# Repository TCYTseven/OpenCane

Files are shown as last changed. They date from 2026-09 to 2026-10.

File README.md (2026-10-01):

<p align="center">
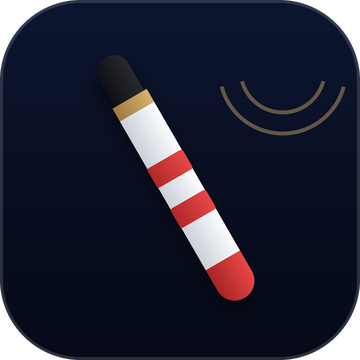
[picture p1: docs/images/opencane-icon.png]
OpenCane app icon: a white cane with red bands on a navy tile
  
</p>

<h1 align="center">OpenCane</h1>

<p align="center"><b>A smart-cane kit that clips an iPhone onto the white cane you already own.</b><br>
LiDAR warnings at waist and head height, haptics through the cane, spatial-audio guidance.<br>
Free where it matters for safety. Open source (MIT).</p>

---

## What OpenCane does

A white cane finds what is on the ground. It misses what is at waist and head height: a low
branch, a truck mirror, a sign bolted at face level. OpenCane clamps an iPhone Pro to the cane and
makes the phone the only computer in the kit:

- **Obstacle detection.** The LiDAR scanner watches the path at waist and head height. The Taptic
  Engine shakes the cane, and "Head height." is spoken before you reach an overhang.
- **Guidance.** GPS and a waypoint engine guide the walk. AirPods Pro play a spatial beacon from the
  direction to walk, and the Apple Watch taps turns and crossings onto the wrist.
- **Hands-free.** Siri, the Action button and "Talk to OpenCane" cover every control, and
  "Where am I" describes the scene, on the phone when there is no network.
- **Hardware you can print.** The mount is 3D-printed ([`hardware/`](hardware/)); nothing needs to
  be bought beyond the phone.

### Free, and OpenCane Premium

| Always free | OpenCane Premium, $49.99/year |
|---|---|
| LiDAR obstacle detection, head-height warnings, drop-off / sign / siren warnings | **Advanced AI object detection**: Hazard watch (cones, barriers, scooters on your route) and people counting |
| Haptics through the cane, spatial audio, speech | **Grok Bot and Family Alerts**: your family hears about a fall, a close call or a low battery |
| Turn-by-turn walking navigation, Apple Watch cues, "Where am I", emergency calling | |

The paywall **never appears during a walk**. Subscriptions run on [RevenueCat](https://www.revenuecat.com).
OpenCane is a social good project, and Premium may be eligible for reimbursement through
insurance, an HSA/FSA or a vision rehabilitation program.

## Screenshots

<p>
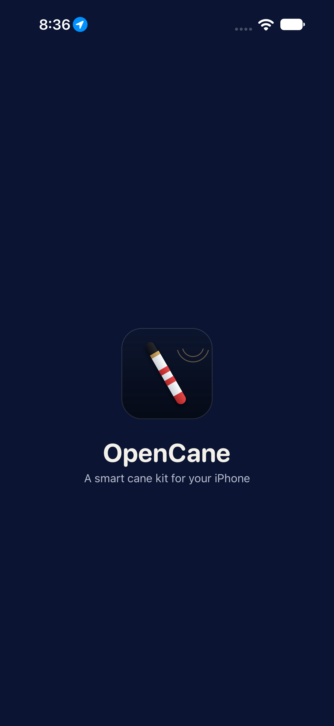
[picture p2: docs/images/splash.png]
OpenCane splash
  
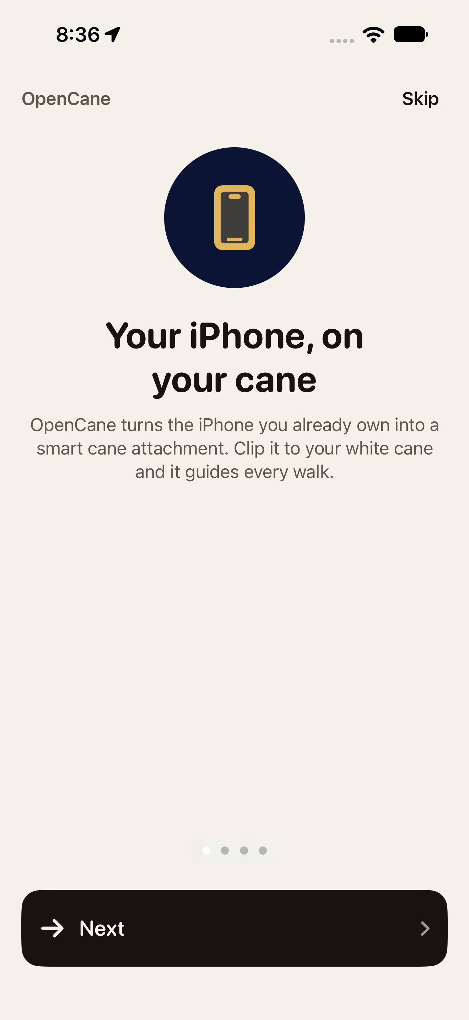
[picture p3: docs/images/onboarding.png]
Onboarding
  
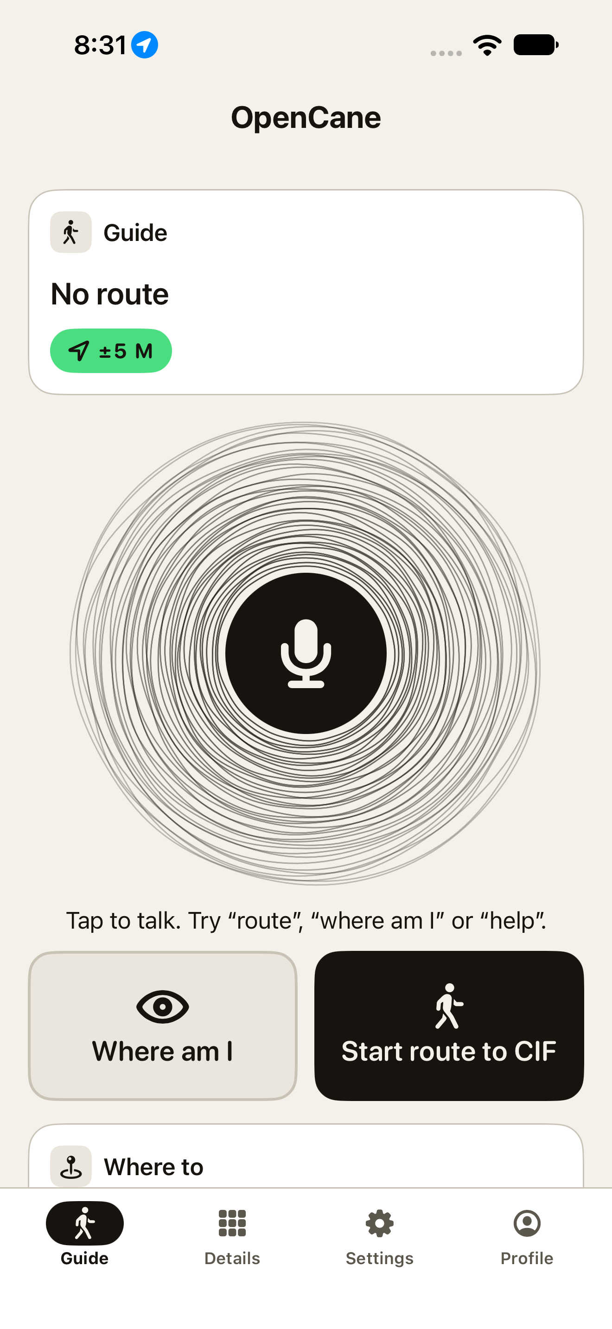
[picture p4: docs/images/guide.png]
Guide
  
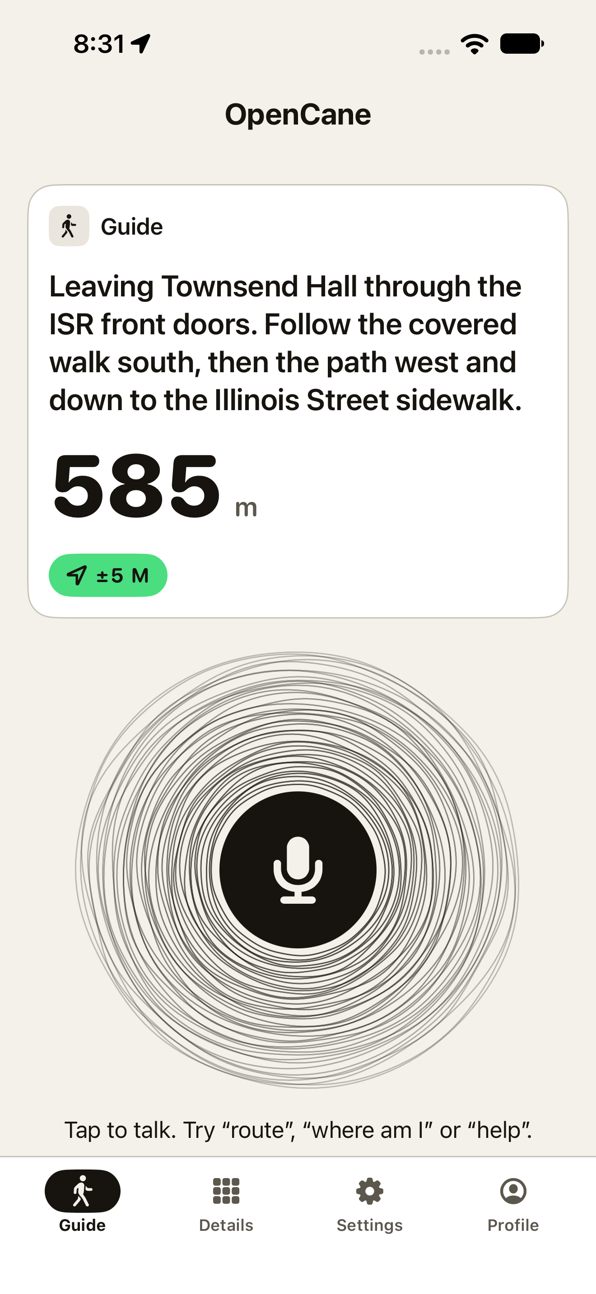
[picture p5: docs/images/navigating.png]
A route in progress
  
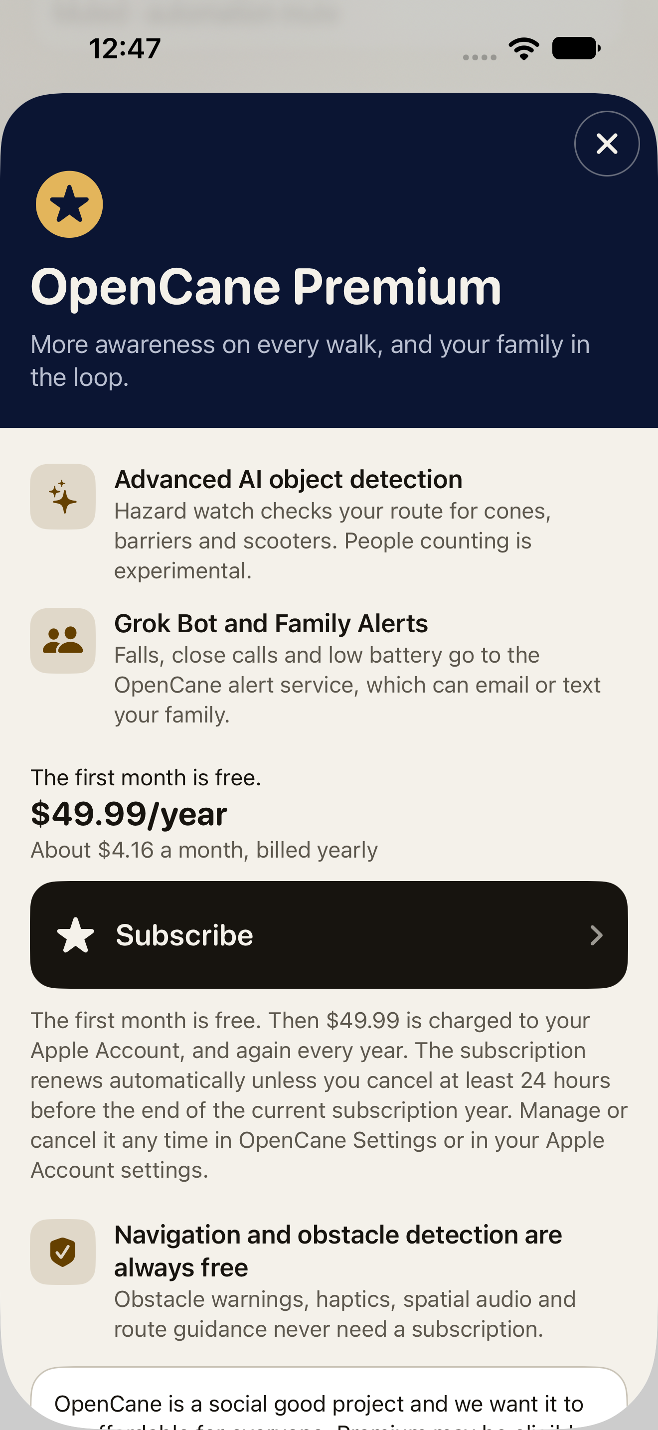
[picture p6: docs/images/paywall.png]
OpenCane Premium paywall at $49.99 a year
  
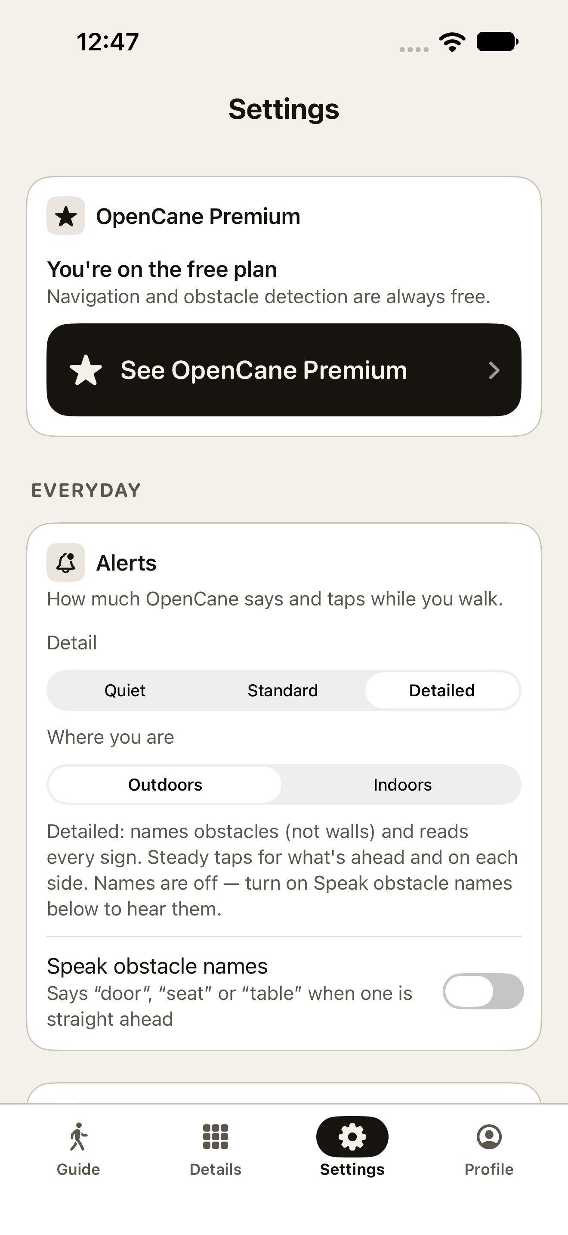
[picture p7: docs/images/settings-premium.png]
Settings showing the free plan
  
</p>

The 1024 App Store icon is [`docs/images/opencane-icon-1024.png`](docs/images/opencane-icon-1024.png).

## Hardware

| Part | Role |
|---|---|
| iPhone with LiDAR (a Pro model; built on an iPhone 17 Pro Max, iOS 27) | The only computer. LiDAR depth, Core Haptics through the cane, GPS + compass, camera |
| Non-metal cane shaft (the prototype uses a 27.65 mm broom handle) | The cane |
| Printed phone mount | Clamps the phone to the shaft: the screwless mount in [`hardware/mount_screwless/`](hardware/mount_screwless/) (print runbook: [`hardware/3d_print_files/README.md`](hardware/3d_print_files/README.md)) |
| AirPods Pro *(optional)* | Spatial-audio beacon, speech, head direction |
| Apple Watch *(optional)* | Wrist taps for turns, crossings and arrival; Repeat / Next / Describe / Recenter |
| Power bank *(recommended)* | ARKit + LiDAR run about 3–4 h on the phone battery |
| Mac with Xcode 27 | Builds and installs. Nothing talks to it at runtime. |

An iPhone without LiDAR installs and guides, and says that obstacle warnings need LiDAR.

## Build and run from a fresh clone

You need a Mac with **Xcode 27** (with the watchOS platform) and **XcodeGen** (`brew install xcodegen`).

```sh
git clone https://github.com/TCYTseven/OpenCane.git
cd OpenCane/ios
make gen        # generates CaneKit.xcodeproj and creates the git-ignored Secrets.plist from the template
make test       # the CaneKitLogic unit tests (no simulator needed)
make sim        # simulator build; the first build downloads the RevenueCat package
open CaneKit.xcodeproj   # then Run the CaneKit scheme on a simulator or your iPhone
```

**Keys** go in `ios/CaneKit/Resources/Secrets.plist`, which is git-ignored and bundled into the app,
so add them before you build. Every key is optional. Without any key the app still runs: the iPhone
voice speaks, "Where am I" answers on the phone, and with no RevenueCat key every feature is
unlocked and Settings says so.

| Key | For |
|---|---|
| `REVENUECAT_API_KEY` | OpenCane Premium. The **public** Apple API key from RevenueCat → Project → API keys (`appl_…`). Never a secret key. |
| `ELEVENLABS_API_KEY` | The natural voice |
| `CUSTOM_*`, `ANTHROPIC_API_KEY`, `GEMINI_API_KEY`, `OPENAI_API_KEY` | The cloud model for "Where am I" and Hazard watch (on-device otherwise) |
| `OPENCANE_GROKBOT_WEBHOOK_URL` / `_KEY` | Family alerts through the Grok Bot routine |

The full list is in [`ios/README.md` §4](ios/README.md#4-secrets-and-permissions).

**On your iPhone:** turn on Developer Mode and pick your team in Xcode (CaneKit target → Signing &
Capabilities), then Run. Or from the command line, put `TEAM` and `DEVICE` in `ios/local.mk` and run
`make run`. [`ios/README.md` §3](ios/README.md#3-build-install-launch) walks through it, and
[`docs/devices_setup.md`](docs/devices_setup.md) covers the AirPods, the watch and an untethered walk.

## Test the paywall

**Fastest: RevenueCat Test Store (simulator or phone, no App Store Connect, no Apple account).**
Put a RevenueCat Test Store key (`test_…`, RevenueCat → Project → API keys) in `Secrets.plist` as
`REVENUECAT_API_KEY`, set up the product, entitlement and offering as in step 1 below under the
project's Test Store app, then from `ios/` run `make uitest-store SIM="<simulator name>"`. It buys
Premium end to end: Details → Hazard watch → paywall ("The first month is free. $49.99/year") →
Subscribe → RevenueCat's "Test valid purchase" → Hazard watch on → Settings "OpenCane Premium is
on". Screenshots land in `ios/build/store-shots`. Or Run from Xcode and tap through it by hand.
The Test Store runs subscription periods fast, so the trial converts in minutes. That is
RevenueCat's test clock, not a bug.

**Judges:** every new install gets the one-month free trial on the annual product. A judge can
also be given Premium: Settings → OpenCane Premium → **Copy support ID**, send it to the team, and
the team pastes it into RevenueCat → Customers → Entitlements → **Grant** `premium`.

A Test Store key only runs the store in a **Debug** build (Xcode Run, the simulator). purchases-ios
stops a Release build that has one ("Wrong API Key", then a crash), so OpenCane skips the store in
that case: a TestFlight build made with a Test Store key opens with every feature unlocked. Use an
App Store key (`appl_…`) for a TestFlight build that should sell Premium.

**Or locally through StoreKit.** Purchases can be tested without App Store Connect, through the StoreKit configuration file
[`ios/StoreKit/OpenCane.storekit`](ios/StoreKit/OpenCane.storekit). It defines one annual
auto-renewing subscription, `opencane_premium_annual`, at $49.99, with a one-month free
introductory offer, and the CaneKit scheme's Run action already selects it.

1. **In RevenueCat:**
   - create a project with an iOS app for the bundle id `com.aritro.canekit`;
   - add the product `opencane_premium_annual`;
   - attach it to an entitlement named `premium`;
   - put it as the Annual package of an offering named `default`, and make that offering current.
2. **In Xcode**, open `ios/StoreKit/OpenCane.storekit`, choose Editor → Save Public Certificate,
   and upload the certificate to the RevenueCat app's settings. That lets RevenueCat validate
   local StoreKit purchases.
3. Put the RevenueCat public API key in `Secrets.plist` as `REVENUECAT_API_KEY`, then build and
   Run from Xcode.
4. Open **Details → Hazard watch** (or Settings → OpenCane Premium → See OpenCane Premium) and
   tap **Subscribe**. The StoreKit test sheet appears. After the purchase the paywall closes and
   the feature is on.
5. To buy again, open Xcode → Debug → StoreKit → Manage Transactions and delete the transaction.
   Refunds, expiry and renewals can be simulated there too.

Settings → OpenCane Premium shows the subscription status, **Restore Purchases** and **Manage
Subscription**. For UI tests without a store, launch with `CANEKIT_PREMIUM=free` or
`CANEKIT_PREMIUM=premium`.

## Tech stack

- **Swift 6** with strict concurrency (main-actor by default), **SwiftUI**, iOS 26 deployment
  target, **XcodeGen** project ([`ios/project.yml`](ios/project.yml)).
- **Apple frameworks:** ARKit + LiDAR scene depth and mesh classification, Core Haptics,
  AVAudioEngine spatial audio (HRTF), AVSpeechSynthesizer, Speech, SoundAnalysis (sirens and horns), Vision, Foundation Models
  (on-device "Where am I"), CoreLocation + MapKit walking directions, WatchConnectivity,
  ActivityKit (Live Activity and Dynamic Island), App Intents (Siri and the Action button),
  HealthKit, StoreKit.
- **RevenueCat** `purchases-ios` for OpenCane Premium: the only third-party package, isolated in
  one file ([`EntitlementManager.swift`](ios/CaneKit/Store/EntitlementManager.swift)).
- **CaneKitLogic**, a pure-Swift package with every rule that has a number in it (lane math, cue
  timing, geofences, the Premium gate) and its Swift Testing suite (975 tests on the last local run; recount with `grep -rhoE '^\s*@Test' ios/Logic/Tests | wc -l`) that also runs on Linux.
- Optional services: ElevenLabs (voice), an OpenAI-compatible, Anthropic, Gemini or OpenAI vision
  model, a Grok Bot routine for family alerts, and Supabase for an opt-in cloud mirror.

## Team

Built at 54FoundersHack in Champaign-Urbana and polished for the RevenueCat Shipaton.
**Aritro**, **Aarav**, **Tejas** (software / iOS app); **Sagar**, **Tommy** (hardware, 3D printing, CAD).

The team is at the University of Illinois Urbana-Champaign and is working with the university
and the [Landuyt Center for Entrepreneurship](https://landuyt.illinois.edu/).

Inside the repo the code is still called **CaneKit**: the Xcode project, targets, the `CaneKitLogic`
module, the `ios/CaneKit/…` paths and the bundle id `com.aritro.canekit`. Only what a person sees
or hears says OpenCane. [`AGENTS.md`](AGENTS.md) → "The name split" explains why.

If you are about to change code, read [Contributing](#contributing) before you edit.

## Recognition

- **First place overall** at 54FoundersHack, 1st of 250.
- **Third place** on the SpaceX track at the same hackathon. SpaceXAI ambassadors are working with the team.
- The launch posts passed **100,000 impressions** on LinkedIn. **More than 100 schools** across the country have written in.
- Funding is in place to keep building.

## Contributing

Read [`AGENTS.md`](AGENTS.md) before the first edit. It wins when documents disagree. The shipped
code wins when a document disagrees with the code: fix the document in the same change.

1. Find the file in [`docs/CODE_REFERENCE.md`](docs/CODE_REFERENCE.md). The data-flow diagram is at the top of that file.
2. A rule with a number in it goes in `ios/Logic` (`CaneKitLogic`) with a Swift Testing test. From `ios/`, `make test` must pass on its own exit code. Never judge it through `| tail`.
3. OpenCane Premium is the one third-party dependency (RevenueCat `purchases-ios`). The gate is [`Premium.swift`](ios/Logic/Sources/CaneKitLogic/Premium.swift), the store client is [`EntitlementManager.swift`](ios/CaneKit/Store/EntitlementManager.swift), the screen is [`PaywallView.swift`](ios/CaneKit/UI/PaywallView.swift), and the walk lock is [`AppModel+Premium.swift`](ios/CaneKit/App/AppModel+Premium.swift). The paywall does not open during a walk. The local product is [`OpenCane.storekit`](ios/StoreKit/OpenCane.storekit): `opencane_premium_annual`, $49.99/year, one month free.
4. Spoken and visible strings say OpenCane. Types, paths, the module and the bundle id stay CaneKit.
5. These paths were removed on purpose. Do not recreate them: `docs/todo.md`, `docs/TEAM_BRIEF.md`, `docs/TEAM_HANDOFF.md`, `docs/ideas.md`, `docs/superpowers/`. The step log is `git log`. [`CHANGELOG.md`](CHANGELOG.md) stays the short submission note.

## Repo map

| Path | What |
|---|---|
| [`AGENTS.md`](AGENTS.md) | **Read before editing.** Hard rules, "How we engineer", commands, and the deliberate behaviours that look like bugs. |
| [`docs/README.md`](docs/README.md) | Index of every doc with when to read it, plus a "Where do I find…" table |
| [`docs/CODE_REFERENCE.md`](docs/CODE_REFERENCE.md) | Map of every file, type and function, with the data-flow diagram |
| [`CHANGELOG.md`](CHANGELOG.md) | Where this submission stands. The step-by-step build log is in git history. |
| [`ios/`](ios/) | The app (code name CaneKit, display name OpenCane): `CaneKit/` iPhone app, `CaneKitWatch/`, `CaneKitWidget/` Live Activity, `Shared/`, `Logic/` SwiftPM package (`CaneKitLogic`, every numeric decision + its unit tests), `CaneKitUITests/`, `project.yml` (XcodeGen), `Makefile`, `scripts/` (test, e2e, cue audit, probes). See [`ios/README.md`](ios/README.md). |
| [`docs/`](docs/) | Design system, hands-free guide, device setup, route evidence, testing plans |
| [`hardware/`](hardware/) | Physical kit: `mount_screwless/` (the live mount, OpenSCAD source), `3d_print_files/` (print runbook; G-code/STLs generated locally), `mount/` (screwed draft + tilt model), `cane_tip/` (printed rolling ball tip) |
| [`scripts/`](scripts/) | Windows mount toolchain (PowerShell + Node): render STLs, slice G-code, verify the screwless mount |
| `firmware/`, `cad/`, `ios/stretch/` | ESP32 grip firmware and OpenSCAD drafts. Stretch / legacy only. |
| [`graphify-out/`](graphify-out/) | Knowledge graph of the repo (code + docs; the committed report lists 6,511 nodes and 15,384 edges, built from `b0db1ebd`). `GRAPH_REPORT.md` lists the communities, `graph.html` opens in a browser (community view, because the graph is over 5,000 nodes). Query it with `graphify query "<question>"`; refresh with `graphify update .` after code changes. |
| `opencane-hardware-brief.html` | One-page hardware brief for a browser |

## Links

- [`AGENTS.md`](AGENTS.md): rules for anyone editing the repo
- [`ios/README.md`](ios/README.md): build, sign, secrets, testing, gotchas
- [`docs/README.md`](docs/README.md): every doc, and where to find things
- [`docs/devices_setup.md`](docs/devices_setup.md): AirPods + Apple Watch + untethered demo checklist
- [`docs/design.md`](docs/design.md): UI and cue design system
- [`docs/cue_design_v2.md`](docs/cue_design_v2.md): research behind the calmer cue design (Steps 35–45)
- [`docs/handsfree.md`](docs/handsfree.md): every voice command and the Action button, for the walker
- [`docs/stress_test_plan.md`](docs/stress_test_plan.md): device tests, failure injection, go/no-go, demo run sheet
- [`hardware/README.md`](hardware/README.md): the printed phone mount (Sagar, Tommy); print runbook in [`hardware/3d_print_files/README.md`](hardware/3d_print_files/README.md)

## License and privacy

OpenCane is released under the [MIT License](LICENSE). The privacy policy is
[`PRIVACY.md`](PRIVACY.md).

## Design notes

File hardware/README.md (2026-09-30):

# hardware/: phone-to-cane mount

> **Printing?** Read [`3d_print_files/README.md`](3d_print_files/README.md) for the print order,
> then generate G-code locally (`scripts/build_stl.ps1` + `scripts/slice_gcode.ps1` on Windows).
> Sliced files are gitignored — they are ~85 MB of build output, not source.

The only new hardware in OpenCane / CaneKit is a mount. It clamps the iPhone 17 Pro Max upright to
the 27.65 mm non-metal stick (measured by the bore rings; it is a broom handle
standing in for a cane), near the grip, with the LiDAR and rear camera facing forward and
~5° down. The phone's own buzz has to be felt through the cane. Everything else (AirPods Pro,
Apple Watch) is off the shelf. This folder replaces the old `cad/` drafts for the phone mount;
those drafts assumed a 12.7 mm cane and an ESP32 grip.

**Sagar owns this folder.** Everything here is a starting point drafted on the software side from
Apple's dimensional drawings and a pitch model. Change the concept, the CAD tool, the geometry and
the print plan with your own ideas and experience. The app needs only four things from any mount:
the phone upright with the rear camera and LiDAR clear and facing forward; the camera 3–8° below
the horizon with the cane held normally (the Mount card shows it live); a firm enough grip that the
phone's buzz is felt in the handle, with nothing magnetic near the phone's bottom edge (compass);
and the shaft out of the camera's view. The product overview is the root
[`README.md`](../README.md).

**Status:** two designs. `mount/` (screwed, this page's quick start) is a
draft nobody has rendered. `mount_screwless/` is the live one: simulated end to end
(`scripts/verify_mount.ps1`: 32 PASS/FAIL lines in a full run, 17 with `-Quick`; all green at Step 25),
sliced, bore rings printed and read; the rest is not yet printed. See `CHANGELOG.md` Steps 21 and 25.

## Files

| File | What it is |
|---|---|
| [`3d_print_files/`](3d_print_files/README.md) | Print-order runbook for the screwless mount. G-code and STLs live here **locally** after `scripts/build_stl.ps1` + `scripts/slice_gcode.ps1`; they are gitignored build artifacts |
| [`mount_screwless/`](mount_screwless/README.md) | The live design: collet clamp + dovetail, zero bought hardware. `screwless_mount.scad` (parts), `coupons.scad` (bore / thread / dovetail fit coupons), `verify.scad` (intersection harness driven by `scripts/verify_mount.ps1`), `PRINTING.md` (operator runbook — read before printing) |
| [`cane_tip/ball_tip.scad`](cane_tip/ball_tip.scad) | Printed rolling ball tip (swivel test, lower, upper, stem), sized to the 27.65 mm prototype stick, not a real cane; rendered by `scripts/build_stl.ps1 -Part swivel_test` etc. |
| `../scripts/` | Windows CAD toolchain for `mount_screwless/` and `cane_tip/`: `build_stl.ps1` (OpenSCAD → binary STL), `verify_mount.ps1` (clearance / mechanism / shell checks), `slice_gcode.ps1` (headless Creality Print slice + material guard), `stl_tools.js` (volume, shells, overhang, support-in-box measurements, node only) |
| [`mount/DESIGN.md`](mount/DESIGN.md) | The design brief: Apple dimensions and sources, what the app needs, requirements, the tilt derivation (**camera 5° down, not 10–20°**), concepts A/B/C, 24 h plan, tooling, print settings, assembly, test protocol |
| [`mount/cane_mount.scad`](mount/cane_mount.scad) | Parametric OpenSCAD model: split collar, rosette hinge with 5° detents and an angle scale, arm, cradle, cap, knob, and an assembly preview. Set `part` to export each STL, already in print orientation. |
| [`mount/test_coupons.scad`](mount/test_coupons.scad) | Bore-fit rings (`pole_d` 27.65 −0.2 / +0 / +0.2 / +0.4), phone-corner fit coupons (gap 0.2 / 0.3 / 0.4), rosette mesh plates |
| [`mount/pitch_model.py`](mount/pitch_model.py) | `python3 mount/pitch_model.py` reproduces the pitch table and the cradle-to-cane clearance check. Edit camera height and FOV after measuring. |

## Quick start (Sagar)

1. Install OpenSCAD (`brew install --cask openscad`; a 2025 development snapshot renders much
   faster). Open `mount/cane_mount.scad` and press F5 with `part = "assembly"`. Look at
   `hinge_angle` 35, 50 and 80. Fix anything it reports.
2. Measure with calipers: the stick Ø where the collar goes, the phone's corner radius
   (`phone_r`), the camera plateau height from the top edge (`plateau_h`), and the button windows.
3. Print `mount/test_coupons.scad` and read it (instructions are in the file header). Set
   `bore_clear`, `clear` and `teeth`.
4. Export and print collar_a, collar_b, arm, cradle, cap and knob in PETG
   (`DESIGN.md` §10).
5. Assemble (`DESIGN.md` §11). Set `hinge_angle` = 95 − cane angle. Run the tests in
   `DESIGN.md` §12 with Aritro.
6. Fine-tune by reading the phone: OpenCane's Mount card shows "Camera tilt N° down · N fps" live.
   Click the hinge until it says **good** (3–8° down) with the cane held the way the walker holds
   it. The same number is in every trip-log `lanes` line as `tilt`.

## Bill of materials

Printed (PETG, light colour; times and masses are estimates, so trust the slicer and the scale):

| Part | Qty | Source | Print | ≈ Mass |
|---|---|---|---|---|
| collar_a (upper half + ear + rosette) | 1 | `cane_mount.scad`, `part = "collar_a"` | ~1.5 h, standing | 30 g |
| collar_b (lower half) | 1 | `part = "collar_b"` | ~1 h, standing | 18 g |
| arm (fin + rosette) | 1 | `part = "arm"` | ~45 min, flat | 16 g |
| cradle | 1 | `part = "cradle"` | ~3.5 h, back down | 30 g |
| cap | 1 | `part = "cap"` | ~30 min, back down | 6 g |
| knob | 1 | `part = "knob"` | ~20 min | 5 g |
| Coupons | 1 set | `test_coupons.scad` | ~40 min | 30 g |

Hardware (no magnets; brass, A4/A2 stainless or nylon only; see `DESIGN.md` R5). **Fridge-magnet
test every screw and nut before use**: reject anything the magnet picks up (cold-worked A2 can
be slightly magnetic).

| Item | Qty | Goes in | Note |
|---|---|---|---|
| M4 × 16 socket-head screw, A2 | 4 | collar clamp | |
| M4 brass heat-set insert, ~8 mm long | 4 | collar_b split face | model hole Ø5.6; check the insert's datasheet |
| M5 × 30 hex bolt, A2 | 1 | hinge | head pressed into the knob (drop of CA) |
| M5 nyloc nut, A2 | 1 | ear pocket | stops the knob backing off from tapping vibration |
| M3 × 8 countersunk screw, A4 (or magnet-tested A2) | 2 | arm → back plate, from the phone side | not nylon: this joint carries the haptics. Heads sit 0.3 mm below the surface; no metal touches the phone |
| M3 brass heat-set insert, 5.7 mm long | 2 | arm root edge | model hole Ø4.0 |
| M3 × 14 screw, nylon preferred | 2 | cap → cradle tabs | next to the phone's top antenna zone |
| M3 nut, nylon preferred | 2 | cradle tab pockets | |
| Right-angle USB-C to USB-C cable, 30–50 cm, plug body ≤ 12 mm | 1 | power | plug turned toward the back of the phone |
| USB-C PD power bank ≥ 5,000 mAh, **not MagSafe** | 1 | strap below the grip or pocket | ≥ 20 cm from the phone (compass) |
| Zip ties 2.5 mm / velcro straps | 5 / 3 | cable routing | slots in the arm and the ear |
| PETG filament | ~150 g | | |
| Paint pen, painter's tape | 1 / 1 | witness marks on screws, hinge, collar | |

Tools: calipers, soldering iron with a heat-set tip, hex keys 2 / 2.5 / 3 mm, 8 mm spanner.

Optional fallback: a Lamicall bike phone holder (15–40 mm clamp, no magnets, ~$30), for a sighted
bench demo only (`DESIGN.md` §7). Do **not** use a Quad Lock MAG or Peak Design SlimLink head:
both put magnets on the phone's back, and the app uses the compass whenever the walker stands
still.

## Who does what

| Who | Owns |
|---|---|
| **Sagar**, **Tommy** (hardware) | Calipers, OpenSCAD render and fixes, coupons, all prints, inserts, assembly, setting the hinge angle, T0 fit, T7 shake, T8 drop, reprints |
| **Aritro**, **Aarav**, **Tejas** (app) | Phone charged; Guided Access (triple-click the side button in OpenCane → Options: Touch, Side Button, Volume Buttons, Keyboards Off, Motion On → Start; then the watch is the only input, see `docs/devices_setup.md` step 4) and the Camera Control setting; app-side tests T2–T6, T9, T10; trip logs; a `CODE_REFERENCE.md` update when the map changes (AGENTS.md rule 10); any `CaneKitLogic` change the tests call for (e.g. `groundSkipFraction`, `DESIGN.md` §13) |
| **Walker** (blindfolded tester) | Holds the cane in their own natural pose for the angle measurement (T1); identifies haptic patterns (T6); walks |
| **Spotter** (sighted teammate) | Walks beside the walker on every outdoor test and films it with a second phone (`ios/README.md`) |

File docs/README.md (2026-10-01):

# Docs index

Every document in the repo, with when to read it. New here, or just pulled? Read the root
[`README.md`](../README.md) (pitch, paywall, and [Contributing](../README.md#contributing)),
then [`AGENTS.md`](../AGENTS.md), then [`ios/README.md`](../ios/README.md).
Open [`CODE_REFERENCE.md`](CODE_REFERENCE.md) when you need a specific file or function.
[`CHANGELOG.md`](../CHANGELOG.md) is the short submission note. The step log is `git log`.

**AI agents:** `AGENTS.md` first (hard rules + "How we engineer"), then `CODE_REFERENCE.md`, then
ask the knowledge graph (`graphify query "<question>"`, see the last row of "Where do I find…").
The code is the newest truth. The step log that used to live in `CHANGELOG.md` is in git history.

**Precedence:** when documents disagree with each other, `AGENTS.md` wins over
`docs/CODE_REFERENCE.md`. When any document disagrees with the shipped code, the code wins and the
doc gets fixed in the same commit. For design tokens, `docs/design.md` is the
spec: when it and `Theme.swift` / `WatchTheme.swift` disagree, fix the Swift. The exception is
screen layout and button labels, where the shipped code (and the tests that pin it) is what's real.

## Every doc

Tracked Markdown plus the one other hand-written doc in the repo
(`opencane-hardware-brief.html`). Nothing else in the repo is documentation; source files document
themselves in their headers (AGENTS.md "How we engineer" 7).

### Repo root

| Doc | Read it when |
|---|---|
| [`README.md`](../README.md) | You want the pitch, the demo, the hardware list, the repo map and the quick start. |
| [`AGENTS.md`](../AGENTS.md) | **Before your first edit, human or AI.** It has the hard rules (concurrency, iOS 26 APIs only, logic lives in `ios/Logic`, secrets, frozen bundle IDs, audio session, speech priorities (rule 8), accessibility-label contract (rule 9), per-commit gate (rule 10)), "How we engineer", the commands, the two false-green traps, the OpenSCAD traps and the "looks wrong but is deliberate" list. It wins every conflict. |
| [`PRIVACY.md`](../PRIVACY.md) | Step 69: the privacy policy the app links to (Settings → About, the paywall). Lists every way data can leave the phone. Change it in the same commit as any new upload path. |
| [`LICENSE`](../LICENSE) | MIT (Step 69). Not Markdown; listed so it is not missed. |
| [`CHANGELOG.md`](../CHANGELOG.md) | Where this release stands and the on-device smoke check. The older step log is in git history. |
| [`opencane-hardware-brief.html`](../opencane-hardware-brief.html) | You want the one-page hardware brief in a browser (added in the Step 21 bore-ring commit). For current print instructions use `hardware/3d_print_files/README.md` instead. |

### iOS app

| Doc | Read it when |
|---|---|
| [`ios/README.md`](../ios/README.md) | You are setting up a Mac, building, signing, installing or testing. It has the day-0 checklist, the Apple spec deviations you must not "fix" (§2, cited by `AGENTS.md` rule 7), every `make` target, secrets and permissions, the automation environment variables, the test layers and counts, how to pull a trip log off the phone, and the depth-map gotchas. |
| [`ios/scripts/streetview/README.md`](../ios/scripts/streetview/README.md) | You want to test the camera features (sign reading, hazard watch, "Where am I") against Google Street View frames of the route, or you need to recapture the git-ignored JPEGs. |
| [`ios/drafts/README.md`](../ios/drafts/README.md) | Rarely. It explains the old iOS 18 starter files, which are not part of any target. |

### `docs/`

| Doc | Read it when |
|---|---|
| [`docs/CODE_REFERENCE.md`](CODE_REFERENCE.md) | You need to find or change code. It maps every file, type and function by module, with the data-flow diagram. |
| [`docs/design.md`](design.md) | You are changing UI, colours or type, or how a cue feels, sounds or shows. §5 maps every cue to its haptic, speech and screen output (§5.1 is speech priorities and the Step 37 talk floor). §6 describes the shipped four-tab layout (Guide / Details / Settings / Profile; §6.8 is the Profile tab, §6.5 has the Family alerts card). §9 is the accessibility-label contract table. |
| [`docs/UX.md`](UX.md) | **Before adding a control of any kind.** Why the interface is a conversation and not a screen: what a button costs a blind walker on a cane-mounted phone (§1), the thesis and its five real failure modes (§2), ten checkable rules (§3), the design — one screen, the two-tier grammar, voice-only mode, input redundancy (§4), what would disprove it (§5). `design.md` still wins on tokens and layout; this wins on *whether a thing should be a button at all*. |
| [`docs/cue_design_v2.md`](cue_design_v2.md) | **Before changing when OpenCane buzzes or speaks.** The Step 35 research: what blind travellers need, where OpenCane violated it, and the proposed calmer cues. Numbers marked **[H]** are hypotheses. |
| [`docs/auditory-load.md`](auditory-load.md) | You are adding or tuning any automatic sound. The Step 30 short research note on blind auditory overload, what OpenCane does about each point, and the open questions for tester walks. `cue_design_v2.md` is the later, fuller research. |
| [`docs/handsfree.md`](handsfree.md) | **You are the walker, or setting the phone up for one.** Every spoken command, what the status answer means, the Settings path for the Action button (and why a locked phone asks to unlock first), what the AirPods stem and Back Tap cannot do, asking a question, and what still needs the screen. |
| [`docs/devices_setup.md`](devices_setup.md) | Before touching the AirPods or the Apple Watch, and before the untethered demo: pairing, Spatial Audio off, the watch app, the voice cache, Guided Access, on-device vision and a symptom → fix table. |
| [`docs/route_isr_cif.md`](route_isr_cif.md) | You are editing `route_isr_cif.json` or re-recording the route on foot. It covers the evidence for every waypoint, OSM node IDs, and which points are still unverified. |
| [`docs/stress_test_plan.md`](stress_test_plan.md) | You are planning device and field tests: facts from the code that change how you test (§0), test levels, the device test matrix (D-tests), failure injection (F-tests), the blindfolded go/no-go checklist and the demo run sheet. |
| [`docs/README.md`](README.md) | This file. |

### Hardware (the printed mount)

| Doc | Read it when |
|---|---|
| [`hardware/README.md`](../hardware/README.md) | You are working on the physical kit (Sagar, Tommy): the four things the app needs from any mount, which of the two designs is live (`mount_screwless/`), the screwed design's files, quick start and bill of materials. |
| [`hardware/3d_print_files/README.md`](../hardware/3d_print_files/README.md) | **You are standing at a printer.** Print order, filament slot, how to read step 1, assembly, what is not settled. G-code/STLs are generated locally (gitignored). |
| [`hardware/mount_screwless/README.md`](../hardware/mount_screwless/README.md) | You are changing the live, no-hardware mount: how it works, build, printer, what to measure before trusting it, the known-unknowns. |
| [`hardware/mount_screwless/PRINTING.md`](../hardware/mount_screwless/PRINTING.md) | Operator runbook for the screwless mount: print list, the one rule, slicing commands, reading the bore rings / thread set / dovetail pair, fitting, calibration. |
| [`hardware/mount/DESIGN.md`](../hardware/mount/DESIGN.md) | You are working on the screwed mount (an unrendered draft) or need the reasoning both mounts share: Apple dimensions, the camera-tilt derivation (3–8° down), concepts, print settings, assembly, test protocol T0–T11. |
| [`cad/README.md`](../cad/README.md) | Stretch / legacy only. The OpenSCAD drafts for the ESP32 grip and sensor pod; they assume a 12.7 mm shaft and are not part of the phone-only demo. |
| [`firmware/README.md`](../firmware/README.md) | Stretch / legacy only. The ESP32 BLE grip firmware, not used for the hackathon. |

### Generated

| Doc | Read it when |
|---|---|
| [`graphify-out/GRAPH_REPORT.md`](../graphify-out/GRAPH_REPORT.md) | You want to know which parts of the repo cluster together, or what a `graphify query` answer is built on. Generated by graphify, never hand-edited. Run `graphify update .` after code changes. The committed graph can lag the tree; trust the code. |

### Outside Markdown

| Where | What |
|---|---|
| [`.github/workflows/ci.yml`](../.github/workflows/ci.yml) | CI. It is **manual-trigger only** (`workflow_dispatch`; Actions tab → CI → Run workflow) because the account's GitHub Actions billing is exhausted. Jobs: Logic tests on Linux, an informational simulator build on macOS. The local `make` gate is authoritative. |
| `ios/Makefile` header | The one-line list of make targets (the full table is `ios/README.md` §3). |
| `scripts/*.ps1`, `scripts/stl_tools.js` (repo root) | Windows mount toolchain: `build_stl.ps1` (render every printable), `slice_gcode.ps1` (headless slicing + verification), `verify_mount.ps1` (the screwless-mount checks), `stl_tools.js` (the STL/G-code measurements they use). Each has a usage header. |
| `~/.claude/plans/phone-is-king-glittery-bee.md` | The approved build plan, on Aritro's Mac only (it is not in the repo). |

## Where do I find…

| I need… | Look here |
|---|---|
| **Build / run commands** | [`ios/README.md` §3](../ios/README.md#3-build-install-launch) (table of every `make` target) and the header of `ios/Makefile`. Run everything from `ios/`. |
| **Signing setup (team, device)** | `ios/local.mk`, which is git-ignored and holds `TEAM = …` and `DEVICE = …`. See [`ios/README.md` §1](../ios/README.md#1-day-0-checklist). |
| **The route file** | `ios/CaneKit/Resources/route_isr_cif.json` (9 waypoints, 989 m). Evidence is in [`route_isr_cif.md`](route_isr_cif.md). The schema is `ios/Logic/Sources/CaneKitLogic/Waypoint.swift`, pinned by `RouteTests.swift`. Other destinations use MapKit via `ios/CaneKit/Navigation/RouteSource.swift`; campus names ("take me to Siebel") resolve through `CampusPlaces.swift`. |
| **Navigation rules (fences, veer, arrival, turn settling)** | `ios/Logic/Sources/CaneKitLogic/GeoMath.swift` (`GeofenceTracker`, `OffCourseDetector`), `CourseSmoother.swift` and `NavSupport.swift` (`TurnSettle`, `StraightWalkDetector`). The engine is `ios/CaneKit/Navigation/NavigationEngine.swift`. The reasons are in `AGENTS.md` → "Things that look wrong but are deliberate". |
| **Speech rules (priorities, interruption, resume, Repeat)** | `AGENTS.md` rule 8 and its deliberate-behaviour list. The code is `ios/CaneKit/Speech/SpeechQueue.swift`, `CueSpeechPolicy` in `NavSupport.swift`, `SpeechLoadPolicy.swift` (optional-speech calm window), `SpeechResume.swift` (Step 37: a cut line resumes from its clause; 0.35 s pause between bands) and `ElevenLabsVoice.swift` (natural voice + cache). The cue table is [`design.md` §5](design.md#5-cue-mapping-every-cue--felt-heard-shown). |
| **Cue detail levels (Quiet / Standard / Detailed × Outdoors / Indoors)** | `CueRules`, `CueLevel`, `CuePlace` in `ios/Logic/Sources/CaneKitLogic/CueProfile.swift` (Step 36; tested in `CueProfileTests.swift`). Persisted as `AppModel.cueLevel` / `cuePlace`, default Detailed + Outdoors; the Settings → Cues card. Research: [`cue_design_v2.md`](cue_design_v2.md). |
| **Haptic patterns** | Phone: `ios/CaneKit/Haptics/HapticPlayer.swift` (obstacles: left 2 taps, right 3, head 2 hard hits, centre Geiger loop 2 Hz at 2 m → 8 Hz at 0.5 m; route: long buzzes, turn left 1, right 2, crossing 3, arrived long-short-long; ground hazard: 4 heavy taps). *When* a cue fires: `CueDecider.swift` + `GeigerRate` in `ios/Logic`. Wrist: the `WKHapticType` map in `ios/CaneKitWatch/WatchModel.swift`. |
| **Watch messages (phone ↔ watch)** | The wire contract is `ios/Logic/Sources/CaneKitLogic/WatchMessage.swift` (JSON under key `"m"`, tested in `WatchMessageTests.swift`). The phone side is `ios/CaneKit/Watch/PhoneWatchLink.swift` and the watch side is `ios/CaneKitWatch/WatchModel.swift`. |
| **Voice commands, Siri, Action button, conversation** | `ios/CaneKit/App/AppIntents.swift`, `App/HandsFreeIntents.swift`, `ios/CaneKit/Conversation/` (`ConversationCoordinator`, `VoiceInputEngine`, `PostStore`), and the Logic side `ConversationModels.swift` / `FastPathIntentClassifier.swift` / `ConversationPrompt.swift` / `QuestionPrompt.swift` / `StatusSummary.swift`. The walker's view is [`handsfree.md`](handsfree.md). |
| **Flashlight / both cameras** | `TorchSwitch.swift` and `LiveView.swift` (`BothCameras`, `FaceTrackingChange`) in `ios/Logic` (Step 34). |
| **Secrets / API keys** | The template is `ios/Secrets.example.plist`. Real keys go only in `ios/CaneKit/Resources/Secrets.plist`, which is git-ignored: never commit or print it. The reader is `ios/CaneKit/Scene/Secrets.swift`. The key list is in [`ios/README.md` §4](../ios/README.md#4-secrets-and-permissions). |
| **OpenCane Premium** | Gate: `ios/Logic/Sources/CaneKitLogic/Premium.swift`. Store: `ios/CaneKit/Store/EntitlementManager.swift` (free month only when `IntroEligibilityStatus.eligible`). Screen: `ios/CaneKit/UI/PaywallView.swift`. Walk lock: `ios/CaneKit/App/AppModel+Premium.swift`. Local product: `ios/StoreKit/OpenCane.storekit` (`opencane_premium_annual`, $49.99/year, free `P1M`). The paywall does not open during a walk. |
| **Testing** | See [`ios/README.md` §5](../ios/README.md#5-testing). Logic tests are in `ios/Logic/Tests/CaneKitLogicTests/` (`make test`; 965 `@Test` annotations in 74 files on the last recount; recount before quoting). UI tests, the screenshot tour and the Dynamic Island tour are in `ios/CaneKitUITests/` (`make uitest` runs all 13, `make tour` and `make island` one suite each). GPS-replay end-to-end runs through `ios/scripts/e2e.py` (`make e2e`). Automation is silent under `CANEKIT_MUTE=1` / `CANEKIT_UITEST=1`. |
| **Accessibility labels the tests depend on** | `AGENTS.md` rule 9 lists them. The details are in `CODE_REFERENCE.md` → module `ui-tests-build` and `design.md` §9. |
| **UI tokens and components** | `ios/CaneKit/UI/Theme.swift` (`CKColor`, `CKFont`, `CKBigButton`, …) and `ios/CaneKitWatch/WatchTheme.swift`. The spec is [`design.md`](design.md), which wins on token values. |
| **Trip log (what happened on a walk)** | `ios/CaneKit/Trip/TripLogger.swift` writes `canekit-<stamp>.jsonl` to the app's Documents folder. Get it with the Files app (On My iPhone → OpenCane), with `cd ios && make audit` (pulls the newest log off the phone in `local.mk` and measures its cue load), or with the `xcrun devicectl … --domain-type appDataContainer --domain-identifier com.aritro.canekit` commands in [`ios/README.md` §5](../ios/README.md#5-testing). |
| **Cue-load numbers for a walk** | `ios/scripts/cue_audit.py` (`make audit`, or `make audit LOG=path`): mounted vs handheld, head band wall vs overhang, cues and spoken lines per minute, replays and resumes. |
| **Hazards (drop-offs, signs, hazard watch, hazard map)** | Decisions: `ios/Logic/Sources/CaneKitLogic/Hazards.swift` (tested in `HazardTests.swift`). App side: `ios/CaneKit/Depth/GroundSampler.swift`, `ios/CaneKit/Scene/HazardScanner.swift`, `OnDeviceVision.swift`, `ios/CaneKit/Trip/HazardLog.swift`, `ios/CaneKit/UI/HazardsCard.swift`. |
| **Mount angle** | `MountTilt` in `ios/Logic/Sources/CaneKitLogic/LaneReport.swift`; live on the Mount card; derivation in `hardware/mount/DESIGN.md`. |
| **Street View mock** | `ios/CaneKit/Depth/FrameReplay.swift`, `ios/scripts/streetview/`, `ios/scripts/vision_probe.swift`, `ios/scripts/sign_probe.swift`, `make uitest-streetview`, `make e2e SCENARIO=streetview`. Not the app: `ios/scripts/streetview_stim.py` (commit `d775d4b`, run by hand) is a stand-alone visualiser over the same frames with its own approximate navigation and template narration. |
| **Project / targets / Info.plist / entitlements** | `ios/project.yml` (XcodeGen). Regenerate with `make gen` only when `project.yml` or the file list changed. Never hand-edit `CaneKit.xcodeproj`. |
| **Open work** | Git history holds the old step checklist. Field testing: [`stress_test_plan.md`](stress_test_plan.md). |
| **The knowledge graph** | `graphify-out/` at the repo root (`GRAPH_REPORT.md` lists the communities; `graph.html` opens in a browser; `graph.json` is the data). Ask it from the repo root with `graphify query "<question>"`, `graphify path "A" "B"` or `graphify explain "X"`. After code changes, refresh it with `graphify update .` (code only) or `/graphify . --update` in Claude Code. Install once with `uv tool install graphifyy` (the build Mac has graphifyy 0.9.44). |

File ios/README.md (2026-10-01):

# OpenCane: the iOS app for the phone-only smart cane

> **The name split.** The product a person sees, hears and says to Siri is **OpenCane** (that is
> `CFBundleDisplayName` in `project.yml`). Everything in the build is still called **CaneKit**: the
> Xcode project, the targets and scheme, `PRODUCT_NAME`, the `CaneKitLogic` module, the
> `ios/CaneKit/…` paths, the Makefile and the frozen bundle ids `com.aritro.canekit*`. That is
> deliberate (AGENTS.md → "The name split"), so every command and path in this file still matches
> the files on disk. Do not rename the code.

This is a native SwiftUI app in Swift 6 with strict concurrency (main-actor default isolation). It
builds against iOS 26 / watchOS 26. Apple frameworks do the sensing and the speech. The one
third-party package is RevenueCat (`purchases-ios`), isolated in
`ios/CaneKit/Store/EntitlementManager.swift`. The hardware is an iPhone 17 Pro Max on iOS 27
(LiDAR, Action button, Camera Control) clamped to a non-metal stick (27.65 mm, measured by the
bore-ring coupons; a broom handle stands in for the cane), plus AirPods Pro and an Apple Watch.
For the demo everything runs **untethered on the phone**. The Mac only signs and installs.

| Target / package | What it is | Bundle ID (frozen) |
|---|---|---|
| **CaneKit** (shown as **OpenCane**) | The iPhone app, and the only computer in the kit | `com.aritro.canekit` |
| **CaneKitWatch** | watchOS companion: wrist taps, Repeat / Next / Describe / Recenter | `com.aritro.canekit.watchkitapp` |
| **CaneKitWidget** | Live Activity (Dynamic Island + lock screen) | `com.aritro.canekit.widget` |
| **CaneKitUITests** | XCUITests + the screenshot tour | `com.aritro.canekit.uitests` |
| **CaneKitLogic** (`Logic/`) | SwiftPM package with every pure decision that has a number in it, plus its Swift Testing tests. Runs without Xcode. | — |

Start with [`AGENTS.md`](../AGENTS.md) (hard rules; it wins every conflict), then
[`docs/CODE_REFERENCE.md`](../docs/CODE_REFERENCE.md), which maps every file, type and function and
has the **data-flow diagram** ([§ Data flow](../docs/CODE_REFERENCE.md#data-flow)). Before the
AirPods, the watch or the untethered demo, read [`docs/devices_setup.md`](../docs/devices_setup.md).
Every other doc is listed in [`docs/README.md`](../docs/README.md).

**Where the work stands.** Obstacle detection, haptics, spatial audio, speech, navigation and
emergency calling stay free. OpenCane Premium (Hazard watch, Name people ahead, and Family Alerts) is the store:
the gate is `ios/Logic/Sources/CaneKitLogic/Premium.swift`, the client is
`ios/CaneKit/Store/EntitlementManager.swift`, the screen is `ios/CaneKit/UI/PaywallView.swift`.
The paywall does not open during a walk. It says the first month is free only when RevenueCat
says this Apple Account is still eligible. Setup for the product, the entitlement `premium` and
the offering `default` is in the root README, "Test the paywall". The short submission note is
[`CHANGELOG.md`](../CHANGELOG.md). The step log is `git log`. There is no `docs/todo.md`.

Recount tests from `ios/` with `grep -rhoE '^\s*@Test' Logic/Tests | wc -l`. Do not quote a count
from this file; it goes stale.

The safety line also includes the route-time `SensorModeInterlock` (face/high-rate changes
cannot restart ARKit during navigation), the generation-fenced `VoiceInputGuard` lifecycle
(route/interruption/permission/engine failures stop push-to-talk and restore playback), GPS freshness
fencing, terminal AR cleanup, and explicit cloud/people-detection consent gates. Recount the
tests with `grep -rhoE '^\s*@Test' Logic/Tests | wc -l` after every merge. Do not keep a frozen count in this file.

## Layout

| Path | Contents |
|---|---|
| `CaneKit/` | The phone app: `App/` (`AppModel` owns every engine; App Intents and hands-free intents), `Conversation/` (voice input, conversational assistant), `Alerts/` (family alerts: `FamilyAlerts`, `GrokBotClient`, `FallWatcher`, `AlertSummarizer`), `Cloud/` (`CloudSync`, `SupabaseClient`), `Depth/`, `Haptics/`, `Speech/`, `Audio/` (beacon, sound watcher), `Navigation/`, `Scene/`, `Trip/` (trip log, `LiveActivityController`, `MedicalProfileStore`), `Watch/`, `UI/` (incl. `ProfilePage`), `Resources/` (`route_isr_cif.json`, assets, your git-ignored `Secrets.plist`) |
| `CaneKitWatch/`, `CaneKitWidget/`, `CaneKitUITests/` | The targets above |
| `Shared/LiveActivity/` | `NavActivityAttributes`, compiled into the app and the widget |
| `Logic/` | `CaneKitLogic`, 77 source files, including `Premium.swift`. Family alerts and safety events: `FamilyAlertPolicy`, `FamilyContacts`, `GrokBotEvent`, `AlertContext`, `FallDetector`, `ThreatWatch`, `ActionRateLimit`. Live Activity: `LiveActivityCoalescer`. Step 47: `TorsoHapticPolicy`, `SceneEngineSummary`. Depth and obstacles: `LaneMath`, `LaneReport`, `DepthSnapshot`, `DepthReadiness`, `MultiCamDepth`, `CueDecider`, `PeopleAhead`, `Hazards`, `SensorModeInterlock`. Cues and speech: `CueProfile` (`CueRules`), `SpeechResume`, `SpeechLoadPolicy`, `SpokenPhrases`, `UtteranceEnd`, `VoicePrefetch`. Navigation: `GeoMath`, `CourseSmoother`, `NavSupport`, `NavigationHealth`, `TripRefreshGeneration`, `Waypoint`, `CampusPlaces`, `DestinationSuggestions`. Scene: `VLMCodec`, `SceneVocabulary`, `CloudSceneGate`, `PeopleDetection`. Hands-free and conversation: `ConversationModels`, `ConversationPrompt`, `FastPathIntentClassifier`, `HeadNodDetector`, `QuestionPrompt`, `StatusSummary`, `VoiceInputGuard`. Devices and app state: `WatchMessage`, `HeadYawSources`, `SoundAlerts`, `SoundRecognitionGuard`, `TorchSwitch`, `LiveView`, `LaunchRecovery`, `StopRouteConfirmation`, `TripLogRecord`. Plus `Tests/` |
| `project.yml` | XcodeGen spec. `CaneKit.xcodeproj` is generated and git-ignored. |
| `Makefile`, `scripts/` | `gen.sh` (project generation), `test.sh` (logic tests), `e2e.py` (GPS-replay end-to-end), `cue_audit.py` (cue load of one trip log, `make audit`), `vision_probe.swift` / `sign_probe.swift` (on-device Vision and sign-reading range against Street View frames), `streetview/` (`frames.json` + git-ignored JPEGs), `streetview_stim.py` (run by hand, no Makefile target: a stand-alone Street View walk visualiser that shells out to `vision_probe.swift` and writes `build/streetview_stim/`; it runs no app code, so use `make e2e SCENARIO=streetview` for what the app says), `appicon.py` (renders the app icon) |
| `Secrets.example.plist` | Template for `CaneKit/Resources/Secrets.plist` |
| `local.mk` | Git-ignored, and you create it: `TEAM` and `DEVICE` for device builds |
| `stretch/`, `drafts/` | Not in any target (old ESP32 BLE client, iOS 18 starter files). Leave them alone. |

---

## 1. Day-0 checklist

These steps are done once per Mac and per phone. On the build Mac they are done: Xcode 27 RC
(27A266a) and XcodeGen 2.46.0 are installed, `ios/local.mk` exists, and the app has been installed
on the phone with `make run` (CHANGELOG Steps 35 and 37). A second Mac or phone needs all of them.

1. Install **Xcode 27 RC** (developer.apple.com/download; ~15 GB installed). The phone runs iOS 27,
   so Xcode 26 cannot deploy to it. The deployment target stays **iOS 26 / watchOS 26**.
   ```sh
   sudo xcode-select -s /Applications/Xcode.app
   sudo xcodebuild -license accept
   xcodebuild -runFirstLaunch
   xcodebuild -downloadPlatform watchOS      # separate download; the watch target fails without it
   brew install xcodegen                     # 2.46.0
   ```
2. Open Xcode once → Settings → Accounts → add your Apple ID. A free **Personal Team** appears. An
   install expires after 7 days, and the team gets 10 App IDs per week. We use 3, so never rename
   bundle IDs. Then run `cd ios && make gen`, open `ios/CaneKit.xcodeproj` once, select the
   **CaneKit** target → **Signing & Capabilities** and pick the Personal Team. That creates the
   Apple Development certificate (until it exists, `security find-identity -v -p codesigning`
   lists nothing). Your **Team ID** is shown in Xcode → Settings → Accounts → the team's details,
   or read it from the certificate and use the `OU=` value:
   ```sh
   security find-certificate -c "Apple Development" -p | openssl x509 -noout -subject
   ```
   The 10 characters in parentheses of an "Apple Development: Name (…)" identity are **not** the
   Team ID.
3. iPhone **and** Watch: Settings → Privacy & Security → **Developer Mode** → on (this reboots).
4. Plug the phone in and open Xcode → Window → Devices. The paired watch shows under the phone,
   which registers its UDID. Watch pairing over Wi-Fi is flaky: if the watch isn't paired within
   30 min, the watch app becomes a day-2 item.
5. Run `cd ios && make devices` and copy the phone's identifier. Then create `ios/local.mk`:
   ```make
   TEAM   = ABCDE12345                # the OU= value from step 2
   DEVICE = 00008150-000A1B2C3D4E5F   # make devices
   ```
6. First install (`make run`), then on the phone: Settings → General → VPN & Device Management →
   trust the developer app.
7. Phone Settings → Action Button → Shortcut → OpenCane → **Talk to OpenCane** (the target
   `docs/handsfree.md` §3 recommends; one press listens, and "What is in front of me?" covers the
   scene) or **Where am I** (scene only). The shortcuts appear after the first launch.
8. Settings → Bluetooth → (i) next to the AirPods → **Spatial Audio: Off** and **Head Tracking: Off**.
   System head-tracking would re-spatialize the beacon. The rest of the AirPods and watch list is in
   `docs/devices_setup.md`.

## 2. Verified spec deviations (don't "fix" these back)

| Spec said | Reality (Apple docs, checked | What CaneKit does |
|---|---|---|
| `AVAudioEnvironmentNode.isListenerHeadTrackingEnabled` | Needs the **Head Pose** capability, which is paid-team only | `CMHeadphoneMotionManager` yaw (relative, drifts) drives `listenerAngularOrientation`. **Recenter** comes from the phone or watch button, or auto-recenter when walking straight (`StraightWalkDetector`: 3 steady fixes, never within 15 m of a crossing). The beacon ignores head yaw until the first recenter after a turn. |
| Watch side button = "next" | There is no API for the side button or a crown *press* | Crown rotation (3 detents within 1 s of the first) + big on-screen Repeat / Next / Describe / Recenter |
| Camera Control press = describe | `AVCaptureEventInteraction` only fires for apps "actively performing capture". Unverified with ARKit owning the camera. | Spike built (`Scene/CameraControlInteraction.swift`; a press is logged as `describe {trigger: cameraControl}` in the trip log — the debug footer that counted presses went in Step 11). The Action button, the watch and the on-screen button are the guaranteed paths. |
| Watch haptics on demand | `WKInterfaceDevice.play` no-ops unless the watch app is frontmost, and `sendMessage` needs reachability | The watch runs a walking `HKWorkoutSession` (HealthKit on the watch target) so cues play wrist-down, with a `WKExtendedRuntimeSession` fallback |
| Haptic rate ∝ 1/distance | `sendParameters` can't retime events | Geiger loop: one pre-built transient player fired on a timer, 2 Hz at 2 m → 8 Hz at 0.5 m |
| One audio session | Mixing `.playback` / `.playAndRecord` / HFP flips AirPods routes | `.playback`, mode `.default`, `[.duckOthers]`, no Bluetooth options. TTS uses the app session. Haptics use `CHHapticEngine(audioSession: nil)`. |
| XcodeGen project | 2.46.0 embeds the watch app in `Watch/` (bug #1613, Xcode 26+) | `scripts/gen.sh` patches the pbxproj after generating. `WATCH=0 scripts/gen.sh` gives a phone-only project. |

Also: mesh classification ("Two meters ahead, door") is an **indoor** feature. LiDAR range is ~5 m and
sunlight kills it. Outdoors the product is the lanes (distance only). Demo doors are at the ISR
lobby and the CIF entrance. Since Step 36 names are spoken only with "Speak obstacle names" on (default
off) and the Settings → Cues place on **Outdoors**: the Indoors place names nothing (`CueRules`).

## 3. Build, install, launch

Everything runs from `ios/` on the command line. You don't need the Xcode GUI after day 0.
`TEAM` and `DEVICE` come from `local.mk`, and you can override either on the command line
(`make build DEVICE=…`).

| Command | What it does |
|---|---|
| `make gen` | `scripts/gen.sh`: `xcodegen generate` + the watch-embed patch, and it copies `Secrets.example.plist` → `CaneKit/Resources/Secrets.plist` if missing. Run it only after `project.yml` or the file list changes. `WATCH=0 scripts/gen.sh` gives a phone-only project. |
| `make test` | `scripts/test.sh`: the `CaneKitLogic` Swift Testing suite (975 tests, 1 known issue, on the last local run). Recount with `grep -rhoE '^\s*@Test' Logic/Tests | wc -l`. Works with the Swift 6 toolchain / Command Line Tools; never touches the simulator or xcodebuild. Extra arguments pass through to `swift test` only when you call `scripts/test.sh` directly (e.g. `scripts/test.sh --filter SpeechResume`). |
| `make build` | Device build, automatic signing, personal team (needs `TEAM` + `DEVICE`) |
| `make install` | `xcrun devicectl device install app` onto the phone |
| `make launch` | `xcrun devicectl device process launch com.aritro.canekit` |
| `make run` | `gen` + `build` + `install` + `launch`. Use this for the phone. |
| `make sim` | Build for the iOS simulator (no LiDAR, haptics or watch there) |
| `make sim17` | Create the **iPhone 17 Pro Max / iOS 27** simulator (`xcrun simctl create`). Run it once: Xcode 27 does not create that device by default. |
| `make sim-grant` | Boot the simulator, install `build/Build/Products/Debug-iphonesimulator/CaneKit.app`, then pre-grant location and motion. A grant before that install is ignored, and the route tests stop on "Location is off for OpenCane". `uitest`, `tour` and `e2e` run it for you. |
| `make uitest` | The whole `CaneKitUITests` target (three XCTest classes, 13 tests) on the iPhone 17 Pro Max simulator. Set a simulator location first (below). |
| `make uitest-store` | Only `CaneKitStorePurchase`: a real RevenueCat **Test Store** purchase of Premium (Details → Hazard watch → paywall → Subscribe → "Test valid purchase" → Hazard watch on → Settings "Renews on …"). Launches without `CANEKIT_UITEST` so the store is live; needs a `test_…` RevenueCat key in Secrets.plist and the network. Shots land in `STORE_SHOTS` (default `build/store-shots`). The simulator keeps the purchase. |
| `make uitest-streetview` | Only `testWhereAmIDescribesAStreetViewFrame`, with `TEST_RUNNER_CANEKIT_FRAME_DIR` pointing at `STREETVIEW` (default `scripts/streetview`), so Street View frames stand in for the camera. Needs the git-ignored JPEGs. |
| `make tour` | Screenshot every screen state (`CaneKitVisualTour`) → PNGs in `SHOTS` (default `build/shots/`) |
| `make island` | Photograph the Live Activity in the Dynamic Island (`CaneKitIslandTour`: compact, expanded, walking, after Stop) → `NN-island-*.png` in `SHOTS`; same prerequisites as `make tour` |
| `make e2e` | Runs `sim` and `sim-grant`, then GPS-replay end-to-end through the real app (`scripts/e2e.py`). `SCENARIO=all` (default, ~20 min: `clean`, `missed_fence`, `gps_jitter`, `wrong_turn`), one of those four, or `streetview` (not in `all`; needs the local JPEGs). It asserts on the app's JSONL trip log. The report and logs go to `build/e2e/`. Always muted. Run it alone: it is a real-time replay. |
| `make audit` | `scripts/cue_audit.py --selftest`, then the cue load of one walk: `make audit LOG=path/to/canekit-….jsonl`, or with no `LOG` it pulls the newest trip log off the phone named by `DEVICE` in `local.mk` (plugged in, unlocked, trusted). Read-only; no simulator. Reports mounted vs handheld, head band wall vs overhang, cues and spoken lines per minute, replays and resumes. |
| `make devices` | `xcrun devicectl list devices` (to find `DEVICE`) |
| `make clean` | Delete `build/`, `CaneKit.xcodeproj` and `Logic/.build` |

Make variables: `SIM ?= iPhone 17 Pro Max` (simulator targets), `SCENARIO ?= all` (`e2e`), `LOG`
(`audit`), `SHOTS ?= build/shots` (`tour`, `island`), `STREETVIEW ?= scripts/streetview`
(`uitest-streetview`), `CONFIG ?= Debug`, `SCHEME ?= CaneKit`. Override any of them per call or in
`local.mk`.

**Simulator location.** `make uitest` and `make tour` need a GPS fix on the simulator, or the route
tests fail for want of one (AGENTS.md, Commands). Set it on the booted simulator before the run:

```sh
xcrun simctl list devices | grep "iPhone 17 Pro Max"      # the UDID in parentheses
xcrun simctl location <udid> set 40.1140,-88.2249
```

`make e2e` does not need this: `scripts/e2e.py` sets and clears the location itself for every
scenario.

The watch app rides inside the phone app and installs through the Watch app on the phone
(Automatic App Install on, or Available Apps → **OpenCane** → Install — the Watch app lists the
display name, not the target name).

## 4. Secrets and permissions

`Secrets.example.plist` is the template for `CaneKit/Resources/Secrets.plist`, which is
**git-ignored**. `make gen` copies it if missing. Never commit the real file. It is bundled into the
.app at build time, so fill in the keys *before* `make run`.

| Key | Meaning |
|---|---|
| `VLM_PROVIDER` | `custom` \| `anthropic` \| `gemini` \| `openai` \| `ondevice`. If empty, the first provider with a key is used (on-device when there is none). `ondevice` uses the phone only, even with a cloud key set. |
| `CUSTOM_BASE_URL` / `CUSTOM_API_KEY` / `CUSTOM_MODEL` | Any OpenAI-compatible chat endpoint (Muse 1.3). The base URL goes without `/chat/completions`. |
| `ANTHROPIC_API_KEY` / `ANTHROPIC_MODEL`, `GEMINI_API_KEY` / `GEMINI_MODEL`, `OPENAI_API_KEY` / `OPENAI_MODEL` | The other "Where am I" providers |
| `ELEVENLABS_API_KEY`, `ELEVENLABS_VOICE_ID`, `ELEVENLABS_MODEL` | Natural voice. The defaults are a warm premade voice and `eleven_flash_v2_5`. |
| *(permission, not a key)* Location **Always** | Asked at the first route start (Step 47). Answer **Always**: with When In Use only, iOS puts its blue location pill in the Dynamic Island during a locked-screen route and demotes OpenCane's Live Activity to the minimal bubble; with Always, OpenCane's own route card owns the island, as Apple / Google Maps do. Declining keeps guidance working (a background session is armed instead). |
| `REVENUECAT_API_KEY` | OpenCane Premium (Step 69.5): RevenueCat's **public** Apple API key (`appl_…`). Empty = no store, every feature unlocked, and Settings says so. Setting up the product, entitlement `premium`, offering `default` and StoreKit testing: root README → "Test the paywall". |
| `OPENCANE_GROKBOT_WEBHOOK_URL`, `OPENCANE_GROKBOT_WEBHOOK_KEY` | Family alerts (§4.1). Copied from the Grok Bot routine's webhook-trigger panel. Empty = the feature is off and says so in Settings. |
| `SUPABASE_URL`, `SUPABASE_PUBLISHABLE_KEY` | Cloud sync (Step 60 MVP): walkers, Medical ID, family contacts, trip summaries, hazards, the family-alert feed. Mobility, settings and the JSONL trip log stay on the phone. Read from the process environment first, then this file (`Cloud/SupabaseClient.swift`). Publishable key only — never the secret key in a client. |
| `CUSTOM_REASONING_EFFORT` | Optional, not in the example plist: the `reasoning_effort` sent to the custom (Muse) endpoint; empty = `low`. |
| `ALERT_MODEL`, `ALERT_REASONING_EFFORT` | Optional. Which cheap model writes `extra.ai_context` on a family alert, and how hard it thinks. Empty model = cheapest of whichever provider has a key (Anthropic → custom → OpenAI). |

With no ElevenLabs key the app uses the system voice. With no VLM key (or `VLM_PROVIDER` =
`ondevice`), "Where am I" answers on the phone: Apple Vision plus Apple's on-device model, or a
template sentence when Apple Intelligence is off. A cloud key adds the cloud model first, with the
on-device describer as the fallback. The no-key UI test checks that "Where am I" never hangs or
crashes. Keys ship in plaintext inside the .app, which is fine for a local install; rotate them
after the event.

### 4.1 Family alerts (Grok Bot)

Cane detections are POSTed as one JSON event to the Grok Bot routine **"OpenCane cane events"**
(folder `opencane-cane-events`), which decides whether to text family. Copy the **Webhook URL** and
**key** from that routine's panel in Grok Bot into `Secrets.plist`:

```xml
<key>OPENCANE_GROKBOT_WEBHOOK_URL</key>
<string>https://…</string>
<key>OPENCANE_GROKBOT_WEBHOOK_KEY</key>
<string>…</string>
```

Both names are also read from the **process environment first**, so an e2e or CI run can point at a
throwaway endpoint without touching the plist:

```sh
export OPENCANE_GROKBOT_WEBHOOK_URL="https://…"
export OPENCANE_GROKBOT_WEBHOOK_KEY="…"
```

The switch is **Settings → Family alerts → "Alert my family"**, off by default (it sends
the walker's position off the phone). **"Send test event"** posts one sample `fall` event and speaks
what came back; it works even while the switch is off, which is how you check the chain before a
walk.

What each detection becomes — thresholds in `FamilyAlertPolicy` (CaneKitLogic, unit-tested):

| Detection | Event | Severity | Rate limit |
|---|---|---|---|
| Periodic GPS | `location` | `info` (chat-only) | one per 120 s |
| Close obstacle (≤ 1.2 m) | `obstacle` | `warn` | one per 60 s |
| Phone battery ≤ 20 % | `low_battery` | `warn` | once per discharge (re-arms above 30 %) |
| Cane went over and stayed down | `fall` | `critical` | one per episode |
| Weapon named in a vision reply | `threat` | `critical` | one per 120 s |
| Route started | `trip_start` | `warn` | once per route |
| Arrived, or Stop pressed mid-route | `trip_end` | `warn` | once per route |
| SOS | `sos` | `critical` | never limited |

⚠ `trip_start` / `trip_end` are `warn` on purpose: the bot only emails family for warn/critical.

⚠ Fall detection ships **on** but its thresholds have never been measured against a real cane
(`FallDetector`). If it cries wolf, Settings → Family alerts → "Detect the cane falling".

⚠ `threat` only means *the vision model's reply named a weapon*. There is no weapon classifier on
the phone; the event quotes the camera rather than asserting one, and the matcher refuses negations
("no weapon"), benign collocations ("knife and fork") and substrings ("gunmetal").

"Send test event" and "Save family emails" are limited to one every 10 seconds each — every POST
starts a bot run, and Save can email the whole family. A refused tap is spoken aloud, not ignored.

#### Who gets alerted

The bot emails a saved list of addresses; the **app never sends mail**. Register the list in
**Settings → Family alerts → Family emails**: add addresses, then press **Save family emails**.
Saving POSTs one event to the same webhook:

```json
{
  "type": "family_contacts",
  "emails": ["mom@example.com", "dad@example.com"],
  "cane_id": "opencane-01",
  "user": "Tejas",
  "timestamp": "YYYY-MM-DDTHH:MM:SSZ",
  "send_test": true
}
```

`send_test` is sent **only on the first list the bot accepts**, so each address gets one "you are on
the OpenCane alert list" email rather than one per edit. Cane events (`fall`, `sos`, `obstacle`, …)
are posted separately and unchanged afterwards — they never carry `emails`, because the bot already
has the list and every copy is one more place it could leak.

Addresses are trimmed, lowercased, de-duplicated and capped at 10 (`FamilyContacts`); an invalid
entry is refused in the UI with the reason, never silently dropped. An empty list is a valid Save —
it tells the bot to stop emailing anyone.

⚠ Registering ignores the "Alert my family" switch (you fill the list in before turning
alerts on) and never goes near the summarizer — a family's addresses are not context for a sentence.

Every event also carries what the phone knew at that moment, in `extra`:

| Field | Example |
|---|---|
| `navigating`, `has_fix` | `true`, `true` |
| `destination`, `instruction`, `distance_to_next_m` | `"ISR to CIF"`, `"Cross Springfield Avenue"`, `42.4` |
| `speed_mps`, `heading_deg` | `0.0`, `272` |
| `battery_pct`, `thermal_state` | `18`, `"fair"` |
| `active_cue`, `last_ground_hazard` | `"clear"`, `"Two meters ahead, drop-off."` |
| `ai_context` | one sentence written by a cheap model from the fields above |

`ai_context` is what makes an alert readable — "Possible fall detected on the route from ISR to CIF
at Cross Springfield Avenue, 42 metres to the next waypoint … battery 18%" instead of bare
coordinates. It is **best effort**: no key, a timeout or an HTTP error costs the event its sentence
and nothing else, and the facts above are sent either way. Switch it off in Settings → Family alerts
→ **Add a short summary**.

⚠ **The model never writes `note`.** A language model is not allowed to be the only factual line in
a safety alert, so its sentence sits in `extra.ai_context` beside the facts it was given and can
always be checked against them. The prompt also forbids the failure a small model reaches for
unprompted: never say the walker is safe or that help is coming, never invent a street or an injury.

⚠ **No SOS control exists yet.** `FamilyAlerts.sos(…)` is written and tested, but nothing calls it
Nothing in the UI calls it yet.

⚠ **HTTP 200 means the bot accepted the call and started a run — not that an SMS was sent.** The bot
decides who to text afterwards, from `severity` and `type`. No string in the app says "family
notified", and none should.

Verify the webhook by hand:

```sh
curl -X POST "$OPENCANE_GROKBOT_WEBHOOK_URL" \
  -H "Authorization: Bearer $OPENCANE_GROKBOT_WEBHOOK_KEY" \
  -H "Content-Type: application/json" \
  -d '{
    "type": "fall",
    "severity": "critical",
    "timestamp": "YYYY-MM-DDTHH:MM:SSZ",
    "lat": 40.1106,
    "lng": -88.2284,
    "note": "Possible fall detected",
    "cane_id": "opencane-01",
    "user": "Tejas"
  }'
```

A success looks like `{"success":true,"runUuid":"…"}`.

Permissions are declared in `project.yml` and prompted on first use:

- **Camera, location, and microphone** are requested on the last onboarding page. After that, `AppModel.start()` asks for location again, which is a no-op if onboarding already answered. `CANEKIT_UITEST=1` skips the launch request.
- **Motion** and **HealthKit** are requested at route start.
- **Health** is requested again on the watch.
- **Camera + LiDAR** are used for obstacles.
- **Speech recognition** is requested with the microphone on that onboarding page, and again the first time voice input is used if it was not granted; the **microphone** alone is also requested when "Listen for sirens and horns" is turned on (`SoundWatcher`).

Every purpose string names the app **OpenCane**, because that is the name the system shows next to
it in the prompt and in Settings ("Turn on Camera for OpenCane"). They live in `project.yml`; edit
them there and re-run `make gen`.

Background modes are `audio` and `location` on the phone and `workout-processing` and `mindfulness`
on the watch. `NSSupportsLiveActivities` is on for the Dynamic Island.

## 5. Testing

The **commit gate** (from `AGENTS.md` rule 10): `make test` and `make sim` must be green. For UI
changes, also run `make uitest` and `make tour` on the iPhone 17 Pro Max / iOS 27 simulator.
"How we engineer" 4 adds `make e2e` (and `SCENARIO=streetview` when the camera path changed). Then
run the Muse review of the diff.

- **Unit tests (`Logic/`, no device):** 975 Swift Testing `@Test` annotations in 74 files under
  `Logic/Tests/CaneKitLogicTests/` (last local `make test`: 975 tests in 29 suites, 1 known issue in `StressTests.geofenceSurvivesHostileGps`). By layer, file names without the `Tests.swift` suffix (count per
  file in parentheses):
  - Depth and obstacles: `LaneMath` (17), `DepthSnapshot` (14), `DepthReadiness` (9, the bounded
    route-start LiDAR gate), `MultiCamDepth` (8), `CueDecider` (27, hysteresis / rate limit / Geiger),
    `TorsoHapticPolicy` (24, Step 47, torso haptics by cue level), `PeopleAhead` (28), `Hazard` (49, ground
    profile, signs, hazard watch, GeoJSON map).
  - Family alerts and safety events: `FamilyAlertPolicy` (10), `FamilyContacts` (14), `GrokBotEvent` (7),
    `AlertContext` (11), `FallDetector` (10), `ThreatWatch` (10), `ActionRateLimit` (5).
  - Scene engine card: `SceneEngineSummary` (20). Live Activity: `LiveActivityCoalescer` (12).
  - Cues and speech: `CueProfile` (17), `SpeechResume` (15), `SpeechLoadPolicy` (7), `SpokenPhrases`
    (15), `UtteranceEnd` (8), `VoicePrefetch` (8), `NavSupport` (26, turn settling, straight-walk,
    spoken-cue policy, crown gesture), `Earcon` (14).
  - Navigation: `GeoMath` (26, skip-ahead, passed-by, arrival gate), `CourseSmoother` (3), `Route`
    (4, MapKit steps → waypoints and the shipped route file), `CampusPlaces` (15),
    `DestinationSuggestions` (16), `IndoorRoute` (45).
  - Scene: `VLMCodec` (11), `SceneVocabulary` (16), `CloudSceneGate` (16).
  - Hands-free and conversation: `ConversationLogic` (28), `NodToTalkFastPath` (2), `HeadNodDetector`
    (7), `QuestionPrompt` (6), `StatusSummary` (17).
  - Devices and app state: `WatchMessage` (3), `HeadYawSources` (18), `SoundAlerts` (40),
    `TorchSwitch` (16), `LiveView` (22), `LaunchRecovery` (7), `TripLogRecord` (2), `PremiumGate` (16),
    `LaunchFlow` (11), `IslandPolicy` (23).

  That layer list is not every file. Count them yourself with `grep -rhoE "^\s*@Test" Logic/Tests | wc -l`. Verify a run by its exit
  code and `error:` lines, never through `tail` (AGENTS.md, Step 27 trap).
- **UI (`make uitest`):** 13 XCTest methods across three classes. `CaneKitUITests` has 10: start, Next, Repeat, Recenter
  and Stop on the demo route; Where am I without a key; Where am I on a Street View frame (skipped
  unless `make uitest-streetview`); the haptic test buttons and the Silence toggle; mount toggles
  persist; the Cues pickers change and restore; VoiceOver labels; the Navigate-to-CIF button on the
  idle Guide; the empty-destination error; and campus suggestions while typing. `CaneKitVisualTour`
  has 2 (`testTour`, `testShipatonShots`) and `CaneKitIslandTour` has 1 (`testDynamicIsland`, `make island`).
  Accessibility labels are a test contract (`AGENTS.md` rule 9).
- **Visual (`make tour`):** one PNG per screen state in `build/shots/`, for review by eye.
- **End-to-end (`make e2e`):** replays the ISR → CIF route in the simulator with
  `xcrun simctl location`. The app auto-starts the route under `CANEKIT_DEMO_ROUTE=1`. Assertions
  run on the trip log: waypoint order, wrist cues, veer cues, "Passed …" lines and arrival. The
  four scenarios are a clean walk, a missed fence, ±6 m GPS jitter and a wrong turn at Goodwin.
  Manual replay: `SIMCTL_CHILD_CANEKIT_DEMO_ROUTE=1 xcrun simctl launch booted com.aritro.canekit`,
  then `xcrun simctl location booted start --speed=4 --interval=1 <lat,lon> …` with the waypoints
  from `CaneKit/Resources/route_isr_cif.json`. The log is `Documents/canekit-*.jsonl` under
  `xcrun simctl get_app_container booted com.aritro.canekit data`.
- **CI (`.github/workflows/ci.yml`) is manual-trigger only** (Actions → CI → Run workflow). GitHub
  Actions billing on the account is exhausted, so pushes don't run it. When run, it does logic tests
  on Linux and an informational phone-only simulator build on macOS. **The local gate above is
  authoritative.**
- **Device only (manual, following each step's "test on device" line in `CHANGELOG.md`):** LiDAR
  scale, haptic feel through the clamp, beacon left/right and head-tracking sign, wrist-down watch
  taps, geofence timing, VLM latency and thermal.
- **Reproducibility:** `TripLogger` writes one `canekit-<ISO 8601 stamp>.jsonl` per session to the
  app's Documents folder (lanes with `tilt`, cues, GPS, heading, thermal, battery, speech dispatches
  and ends, `cue_profile`, hazards). The hazard map is `Documents/hazards/hazards-<session>.geojson`.
  Film every outdoor test with a second phone. Get the log off the phone in any of three ways:
  - Files app → On My iPhone → OpenCane (`UIFileSharingEnabled`), then AirDrop.
  - `make audit` pulls the newest log and measures it (it prints where it saved the copy).
  - By hand, with the phone plugged in, unlocked and trusted (`DEVICE` from `make devices`):
    ```sh
    xcrun devicectl device info files --device <DEVICE> \
      --domain-type appDataContainer --domain-identifier com.aritro.canekit --subdirectory Documents
    xcrun devicectl device copy from --device <DEVICE> \
      --domain-type appDataContainer --domain-identifier com.aritro.canekit \
      --source Documents/canekit-<stamp>.jsonl --destination ./canekit-<stamp>.jsonl
    ```
  In the simulator the same files are under
  `$(xcrun simctl get_app_container booted com.aritro.canekit data)/Documents/`.
- **Go / no-go before a blindfolded ISR → CIF walk.** Any miss means a sighted demo only.
  - GPS accuracy ≤ 20 m for 30 s at the ISR door. Fences and veer cues pause above 20 m, and the
    app says so.
  - A wall at 1 m reads 0.8–1.2 m in all six tiles.
  - The head cue re-fires with a hand overhead, and "Head height." is spoken.
  - Beacon left/right is correct after Recenter.
  - The watch tap is felt wrist-down.
  - Repeat on the watch re-speaks the last line.
  - Arrival fires at CIF east within 20 m.
  - Battery is > 40 % and thermal is nominal or fair.
  - A route start speaks the warm-up state and waits for trusted LiDAR depth; on a fast healthy
    session, the three-frame bar clears in well under a quarter second after the first good reports.
  - A spotter is assigned and the kill-word ("stop") is rehearsed.

### Automation environment variables

The app reads these at launch (`ProcessInfo.processInfo.environment`). In the simulator pass them
with the `SIMCTL_CHILD_` prefix (`SIMCTL_CHILD_CANEKIT_MUTE=1 xcrun simctl launch booted
com.aritro.canekit`); for XCUITests set them in `app.launchEnvironment`, or as `TEST_RUNNER_…` in
xcodebuild's environment (the Makefile does this). None of them is set on a normal launch.

| Variable | Effect | Set by |
|---|---|---|
| `CANEKIT_MUTE=1` | `SpeechQueue.muted`: speech keeps its timing and trip-log records but makes no sound, and the beacon stays silent. Automation must never make noise on the Mac (AGENTS.md "How we engineer" 4). | `scripts/e2e.py` |
| `CANEKIT_UITEST=1` | Everything `CANEKIT_MUTE` does, plus `AppModel.start()` skips the location permission request. | `CaneKitUITests`, `CaneKitVisualTour` |
| `CANEKIT_DEMO_ROUTE=1` (or the `--demo-route` argument) | Starts the bundled ISR → CIF route at launch. The argument exists because `devicectl` launches on a device sometimes dropped environment variables. | `scripts/e2e.py`, manual replays |
| `CANEKIT_FRAME_DIR=<dir>` | Simulator only: `FrameReplay` uses the Street View frame nearest the GPS position as the camera (needs `frames.json` in `<dir>`). | `make uitest-streetview`, `e2e.py --scenario streetview` |
| `CANEKIT_HAZARD_WATCH=1` | Turns the hazard watch on without touching the UI. | `e2e.py --scenario streetview` |
| `CANEKIT_DESCRIBE_EVERY_WAYPOINT=1` | Asks "Where am I" at the start and at every waypoint. | `e2e.py --scenario streetview` |
| `CANEKIT_SHOTS=<dir>` | Where `CaneKitVisualTour` writes its PNGs (test runner side). | `make tour` |
| `CANEKIT_SENSOR_PROBE=1` (or `--sensor-probe`) | Debug: a one-shot "what can run with LiDAR" measurement before `DepthEngine` starts; results are `probe_*` trip-log records. | by hand |
| `CANEKIT_SHOW_ONBOARDING=1` | Step 69: shows first-launch onboarding even under automation or after it was completed (a UI test of the pages). Without it, automation never sees onboarding or the splash (`LaunchFlow`). | by hand / a future UI test |
| `CANEKIT_PREMIUM=free` / `premium` | Step 69.5: forces the OpenCane Premium state without RevenueCat (screenshots and UI tests of the locked / unlocked screens). Unset = the real store, or everything unlocked when there is no `REVENUECAT_API_KEY`. | by hand / a future UI test |
| `CANEKIT_SENSOR_SELFTEST=1` (or `--sensor-selftest`) | Debug: shows the sensor self-test buttons on the Hazards card. Never in the demo build. | by hand |

## 6. Gotchas

- **Depth map orientation.** `sceneDepth.depthMap` is 256×192 landscape in sensor orientation.
  With the phone upright, the buffer is the scene rotated 90° CCW: `bufferX = sceneY`,
  `bufferY = (H-1) - sceneX`. The Phone on cane toggles "Phone is upright" and "Mirror left /
  right" exist for this. Verify with a hand at the left edge.
- **CVPixelBuffer.** Lock before reading, unlock in `defer`, and use `CVPixelBufferGetBytesPerRow`
  (rows are padded). Retain exactly one camera buffer for the snapshot. Retaining `ARFrame`s makes
  ARKit drop frames.
- **Ground and mount tilt.** The bottom 25 % of the upright image is skipped (`LaneMath`
  `groundSkipFraction`) so pavement isn't a permanent obstacle. There is no gravity correction, so
  the mount must aim the camera 3–8° below the horizon: the Mount card shows "Camera tilt N° down"
  live. Fix the mount before touching `groundSkipFraction`.
- **Sweep gate.** Frames with |gyro| ≥ 0.6 rad/s are untrusted. The cue decider freezes and emits
  nothing, and the grid pill reads SWEEPING.
- **Foreground only.** ARKit stops when the app is backgrounded or the screen locks. The app sets
  `isIdleTimerDisabled = true`. Use Guided Access for the demo (how to arm it:
  `docs/devices_setup.md`, untethered demo step 4). Keep
  a power bank on the strap, since ARKit + LiDAR run ≈ 3–4 h.
- **Thermal.** `.serious` or worse turns off mesh classification, and with it the obstacle names.
  Lanes and haptics never stop. (Obstacle names are also off by default since Step 36; when they
  are on, `CueRules.allowsName` decides: Quiet and the Indoors place name nothing, Standard names
  doors while a route guides, Detailed names everything except walls.)
- **xcodebuild hangs after "Test Suite … passed".** Seen with `make tour` / `make uitest-streetview`
  when old test-runner processes were left on the simulator (hours old). The tests themselves had
  passed. Fix: `xcrun simctl shutdown all`, then rerun. `make e2e` relaunches the app itself and is
  not affected.
- **Fence radii come from the route file.** Most waypoints use 15 m, turns (WP3, WP6, WP8) use
  12 m and arrival (WP9, CIF) uses 20 m. Before you touch a fence, veer or speech rule, read
  `AGENTS.md` → "Things that look wrong but are deliberate".

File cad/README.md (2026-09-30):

# Cane printable drafts (OpenSCAD), legacy ESP32 era

**Legacy, do not print for the demo.** These drafts are from the ESP32 plan (XIAO grip module,
VL53L1X sensor pod, coin motors), which the phone-only CaneKit app replaced. They also assume a
12.7 mm aluminum/graphite shaft; the prototype stick is **27.65 mm, non-metal** (a broom handle,
measured by the bore rings; the earlier 28.75 mm reading was wrong), so none of the
clamps below fit it. The phone-to-cane mount now lives in [`hardware/`](../hardware/README.md): the
live design is [`hardware/mount_screwless/`](../hardware/mount_screwless/) (slice locally — see
[`hardware/3d_print_files/README.md`](../hardware/3d_print_files/README.md)); [`hardware/mount/`](../hardware/mount/)
is the screwed alternative. The firmware these housings were for is [`firmware/`](../firmware/README.md),
also stretch only. No script renders these files (`scripts/build_stl.ps1` covers `hardware/` only).

All three files are UNRENDERED drafts written without a running OpenSCAD.
Open each, press F5, and check pockets against the real parts before exporting STL.

- grip_module.scad — split grip sleeve: XIAO ESP32-S3 bay, 500mAh LiPo bay, 2x 10mm coin motor pockets, M3 join, wire channels.
- chest_plate.scad — lanyard/chest plate with GoPro-style 3-prong mount. Hedge if phone-on-cane blur is a problem.
- sensor_pod.scad — hooded tube clamp for VL53L1X, aims 35° down the shaft.

External parts to grab as-is (sized for the old 12.7 mm shaft):
- Phone clamp (GoPro-compatible): https://www.printables.com/model/145012
- Pole grip, set poleDiameter=12.7 (the prototype stick would need 27.65): https://github.com/j-h-a/go-pro-mounts
- Parametric tube clamp: https://www.printables.com/model/1214545-print-in-place-tube-clamp-fully-parametric

Key dimensions used: shaft 12.7 mm (Ambutech aluminum/graphite; not the demo stick, which is 27.65 mm non-metal), VL53L1X breakout 25.5x17.5x4.6, LiPo 36x29x4.75, XIAO ESP32-S3 21x17.5.

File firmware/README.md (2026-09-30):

# CaneKit grip module firmware

> **Stretch / history only — not used by the app.** The ESP32 grip was cut on when
> OpenCane went phone-only (`AGENTS.md`: no ESP32, no external sensors). Nothing in the iOS targets
> talks to it; the only client ever written is `ios/stretch/CaneBLE.swift` (in no target), which
> speaks the protocol below. The housings are the legacy drafts in [`cad/`](../cad/README.md).
> Never built in CI, no automated tests; the local fail-safe thresholds were never tuned on a cane.

BLE haptic grip for a smart-cane retrofit: two coin ERM motors driven from a phone over
Nordic UART Service, optional VL53L1X ground-distance sensor, and a local fail-safe
drop-off / step-up alert when no phone is connected.

Files: `canekit_grip.ino` (BLE, motors, parser, telemetry, fail-safe), `tof.h/.cpp`
(VL53L1X, compile out with `HAS_TOF 0`), `platformio.ini`.

## Build — Arduino IDE

1. File > Preferences > Additional boards manager URLs:
   `https://raw.githubusercontent.com/espressif/arduino-esp32/gh-pages/package_esp32_index.json`
2. Boards Manager: install **esp32 by Espressif Systems** (3.x tested API; 2.x also guarded).
3. Library Manager: install **NimBLE-Arduino** (h2zero, 2.x) and **VL53L1X** (Pololu).
4. Board: **XIAO_ESP32S3** (Tools > Board > ESP32 Arduino). Fallback: **ESP32C3 Dev Module**
   with *USB CDC On Boot: Enabled* for the SuperMini.
5. Open `canekit_grip.ino` (the folder must be named `canekit_grip` for the IDE — rename the
   folder or copy the three source files into `canekit_grip/`), upload, open Serial Monitor @ 115200.

No ToF fitted? Set `#define HAS_TOF 0` in `tof.h` (or `-DHAS_TOF=0` in platformio.ini);
the sketch also runs fine with `HAS_TOF 1` and no sensor — it just reports `D:-1`.

## Build — PlatformIO

```
pio run -e xiao_esp32s3 -t upload
pio device monitor
```
`-e esp32c3_supermini` for the fallback board.

## Wiring

Pin numbers are GPIO numbers. XIAO ESP32-S3 mapping verified against the Seeed wiki
(XIAO ESP32S3 pin multiplexing page): D0=GPIO1, D1=GPIO2, D2=GPIO3, D4=GPIO5 (SDA),
D5=GPIO6 (SCL), user LED = GPIO21 (active low).

| Signal | XIAO ESP32-S3 | ESP32-C3 SuperMini (unverified) |
|---|---|---|
| Left motor drive  | D0 / GPIO1 | GPIO2 |
| Right motor drive | D1 / GPIO2 | GPIO3 |
| ToF SDA | D4 / GPIO5 | GPIO6 |
| ToF SCL | D5 / GPIO6 | GPIO7 |
| Battery sense | D2 / GPIO3 (opt.)  | GPIO0 (opt.) |
| Status LED | on-board GPIO21 | on-board GPIO8 |

Motor driver, one per motor (low-side NPN switch, e.g. 2N2222 / BC337 / S8050):

```
3V3 ----+----- motor(+)
        |        motor(-) ----+---- NPN collector
   1N4148 (cathode to 3V3,    |          NPN emitter ---- GND
   anode to motor(-))        0.1uF      NPN base ---- 1k ---- GPIO (D0 / D1)
        |                     |
        +---------------------+
```

- 1N4148 flyback across the motor: cathode (band) to 3V3, anode to the collector side.
- 0.1 uF ceramic directly across the motor terminals (brush noise).
- Coin ERMs pull ~60-90 mA each; the XIAO 3V3 regulator handles two. If you see BLE
  resets when both buzz, add a 100 uF cap on 3V3 or feed the motors from VBAT instead.

VL53L1X: VIN->3V3, GND->GND, SDA->D4, SCL->D5. Pololu carrier has on-board pull-ups.
Mount it pointing at the ground ~40-60 cm ahead of the tip.

Battery (optional): the XIAO ESP32-S3 has no battery ADC by default. Wire BAT+ through
two equal resistors (e.g. 100k/100k) to GND, tap the midpoint to D2, and uncomment
`#define BAT_SENSE_PIN 3` in the sketch. Without it the firmware reports `B:-1`.

## Protocol (NUS, device name `CANE`)

Service `6E400001-B5A3-F393-E0A9-E50E24DCCA9E`, RX write `6E400002-...`, TX notify `6E400003-...`.

| Command | Meaning |
|---|---|
| `H:{L,R,B}:{1-4}:{ms}` | Buzz left/right/both at intensity 1-4 (40/60/80/100 %) for `ms` (1-10000). Up to 4 commands wait behind the one playing; extra ones are rejected (logged on Serial, nothing sent back over BLE). |
| `P:1` | Double pulse, both motors |
| `P:2` / `P:3` | Left / right triple pulse |
| `P:4` | STOP: flush the queue, then one long buzz on both |
| `S:1` / `S:0` | Silence on / off. `S:1` flushes the queue and stops the motors; while on, commands are accepted and dropped. ⚠ It persists across a disconnect and also mutes the local fail-safe alerts until `S:0` or a reboot. |

Command letters are case-insensitive; one command per line (LF or CR; 47 characters max, longer
lines are truncated). Anything else is rejected on Serial.

Telemetry, every 100 ms while connected: `D:<mm>,B:<pct>\n` (`-1` = unknown; `B` refreshes once a second).

LED: solid = connected, short blip each second = advertising, fast blink = local
fail-safe mode (no phone for 5 s and ToF present). In local mode both motors buzz when
the ground distance rises > 250 mm above baseline (drop-off: double pulse) or falls below 60 % of it
(step-up: one 400 ms buzz), at most once per 1.5 s. Baseline = median of the last 20 readings
(one per 50 ms, so ~1 s) whenever their spread is <= 40 mm; it keeps its old value while readings
are unsettled, so any surface held steady for ~1 s becomes the new baseline.

## Testing with nRF Connect (Android / iOS)

1. Scan, connect to **CANE**. The board LED goes solid.
2. Expand the Nordic UART Service, tap the down-arrow on the TX characteristic
   (`...0003`) to enable notifications. You should see `D:-1,B:-1` (or a real distance)
   arriving 10x per second — switch the value display to Text/UTF-8.
3. Tap the up-arrow on RX (`...0002`), set the type to **Text**, enter `H:B:4:500` and
   send. Both motors buzz at full for 500 ms. A trailing newline is ideal; without one
   the line is parsed after 150 ms anyway.
4. Try `P:1`, `P:2`, `H:L:2:2000` then `H:R:4:200` (queued), `S:1` then `P:4` (nothing),
   `S:0`. Serial Monitor echoes every line and any rejection.
5. Disconnect and wait 5 s: with a ToF attached the LED starts blinking fast; sweep the
   sensor over a table edge to trigger the drop-off buzz.

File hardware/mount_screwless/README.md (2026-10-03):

# hardware/mount_screwless/: the no-hardware phone mount

> **At a printer?** Generate G-code locally (see [`../3d_print_files/README.md`](../3d_print_files/README.md)),
> then follow [`PRINTING.md`](PRINTING.md).

**Sagar owns this folder.** It is an alternative to [`../mount/`](../mount/), not a
replacement — pick whichever one is fitted on the day and say so in `CHANGELOG.md`.

The difference is the bill of materials. `../mount/` needs four M4 screws, four M4
brass heat-set inserts, an M5 bolt, an M5 nyloc, two M3 countersunk screws, two M3
inserts, two M3 nylon screws and two nylon nuts, plus a soldering iron with a
heat-set tip to fit them. This folder needs **none of that**. Four printed parts (six
if you choose the ball joint), a cane, and a phone.

That is the pitch, not a shortcut: the iPhone already is the sensor suite, the
compute, the battery and the speaker. If the retrofit that turns an ordinary white
cane into a smart cane is *one spool of filament and nothing else*, then anyone with
a printer can make one, and the reason a smart cane costs $850 stops being obvious.

**Status:** designed, rendered clean, and **simulated** - every
pair of parts that must not touch has been intersected in the model and comes out empty,
the thread has been driven through its travel in the model, and each printable is a single
shell in its print orientation (`.\scripts\verify_mount.ps1`, 30 checks, all green).
**Still never printed as a whole.** The bore rings have been printed and read (`pole_d` =
27.65, settled - see `CHANGELOG.md` Step 21), and one thread coupon pair was printed and jammed two
turns in; that is now explained and fixed twice over (see the thread note below). Every other
clearance is still a guess until the coupons come off the bed, and nobody has put this on a real
cane - the prototype shaft is a **broom handle**; real long canes are 9.5–13 mm at the tip end.

> **Read [`PRINTING.md`](PRINTING.md) before you send anything to a machine.** It is the
> operator runbook: which file, which filament slot, which temperatures, in what order,
> and how to read each coupon.
>
> **The thread did not exist.** `linear_extrude(twist=)` maps *angle*
> to height, so the tooth — drawn as a flat offset in y — came out 0.031 mm thick and
> sliced away to a smooth cylinder. The collar's clamp was a plain tube. It is rewritten
> as an angular sector and measures 0.62–0.75 mm, but **that has never been printed.**
> The thread coupon is the first physical proof either way, and if the ring will not
> thread onto the stub, do not print the collar.
>
> **The first printed thread pair jammed two turns in, and the model says
> why - twice.** First, the tooth was not the tooth the parameters described: the flank was a
> straight chord that dipped inside the minor circle, so the union with the core swallowed it and
> the printed root was 0.74 mm instead of 1.5 (Step 21 measured it; the profile is polar now).
> Second, on the real collar the ring could not have reached the shoulder even with a perfect
> thread: lift the ring in the model and turn it with the helix, and at every height from
> 6 mm up there was 0.165 cm³ of ring inside collar: the collar's cone started at the
> thread's *major* radius, 0.75 mm outside the ring's thread crests, so the ring's own
> internal thread ploughed into the cone's base with 3.8 mm still to go. The cone now
> starts 0.10 mm *inside* the crest radius (`cone_relief`) and the ring's threaded band
> passes it freely; the sweep is empty until the cone is meant to engage. The thread is cut
> to nut 3 of the four-nut coupon, [0.45 radial, 0.45 axial] (the pair that jammed was
> [0.35, 0.25]; 0.125 mm per flank is under one line of over-extrusion), and its flank is 60°
> from vertical now (was 69°, which printed every lower flank in air). With real 60° flanks the
> radial clearance also becomes axial slack - about 0.49 mm per flank in total - so **a loose ring
> rocks about 1 mm at the top; that is normal and disappears once it bears on the cone.**
> **On the cane the ring is supposed to stop about 3 mm short of the shoulder** - that is the
> collet gripping. If it reaches the shoulder with the cane in, the bore is too big.

The assembly preview (`part = "assembly"`) is a look, not a test. It draws the
ghost cane, the ghost phone and a red ray along the rear camera's optical axis, and three
faults were found by looking at it: the dovetail sockets were on the wrong axis, the
collar's pad was shorter than the dovetail, and the phone's bottom corner cleared the
shaft by 1.1 mm. Render it after any change; if the red ray does not come out roughly
horizontal, tipped slightly down, and miss the shaft, the arm is wrong. **But it cannot
show an overlap** - two parts drawn through each other look like two parts. It was hiding 6.9 cm³ of arm inside the phone. The test is `verify.scad` run by
`.\scripts\verify_mount.ps1`: it renders the *intersection* of every pair that must not
touch (empty = pass), the intersections that must exist (the collet squeeze), the thread
lifted and turned through its travel, and the ring as the arm's lock, and it counts shells.
Run it after any change. It takes two minutes.

## Print these in this order

Do not skip to step 3. The three clearances decided in steps 1 and 2 are printer-
and cane-specific, and every part depends on them.

| # | Render | Solid volume | What it settles |
|---|---|---|---|
| 1 | `coupons.scad`, `what="bore"` | ~20 cm³ | **the cane diameter itself** — see the conflict below |
| 2 | `coupons.scad`, `what="thread"` then `"dovetail"` | 12 + 31 cm³ | `thr_clear`, `dt_clear` |
| 3 | `collar` + `ring` | 36 + 24 cm³ | the clamp |
| 4 | `arm` + `cradle` | 38 + 33 cm³ | the rest |

Volumes are measured off the rendered STLs at 100% infill. At 25% gyroid the real
mass is well under half.

**Sliced, per part —** - see the table in [`PRINTING.md`](PRINTING.md).
Every plate is a separate file written by `slice_gcode.ps1`, which is also the only thing that
knows to turn support on for the cradle. The old `opencane_mount_plate.3mf` (six parts, 4 h 31)
predates the redesign below and must not be printed.

**Support: none, except the cradle.** The cradle stands on its dovetail block, so its
back plate sits 5 mm off the bed, and the rails and corner caps with it. The block has a
45-degree flare that carries the plate around the block; the rest wants support - "on
build plate only" is enough, and it lands on the outer face of the back plate, which
nothing touches in use. `slice_gcode.ps1` turns it on for the cradle by itself, sets
`max_bridge_length` to 30 so the socket's 24.5 mm roof is bridged instead of being filled
with support (Orca's default is 10, and it did fill it), and refuses to write a cradle
file without support. Every other part is drawn so no downward face passes 45 degrees,
and the dovetail flanks are exactly 45 for that reason - they were 67, which put the
lower flank of every tenon and socket in the air.

Coupons carry **notches, not numbers**: count the notches, fewest = smallest. OpenSCAD's `text()` needs fontconfig, which the portable Windows snapshot
does not ship, so text silently renders as nothing and you get four identical
unlabelled rings. Notches also read by thumb, which is on-brand here.

## Build

```powershell
.\scripts\build_stl.ps1
```

STLs land in `stl/`, which is gitignored. `-Part collar` does one part; `-Png` also
writes previews.

**Use a 2025 snapshot of OpenSCAD, not the winget release.** The 2021.01 build that
`winget install OpenSCAD.OpenSCAD` gives you has no Manifold backend and takes
**6 minutes 52 seconds** to render the collar. The snapshot does the same part in
**0.3 s**. One is a workable edit loop and the other is not. Download the portable
zip from <https://files.openscad.org/snapshots/> and unzip into `%USERPROFILE%\Tools\`;
the build script finds it there on its own. One is already unzipped at
`%USERPROFILE%\Tools\OpenSCAD-2025.09.15\`.

## Printer

Sliced for the **Creality SPARKX i7** (the profile is already in Creality Print 7.2):

- build volume **260 × 260 × 255 mm** — the largest part, the coupon plate, is
  174 × 195 mm, so everything fits flat with room
- 0.4 mm hardened steel nozzle, Klipper; default profile
  `0.20mm Standard @SPARKX i7 0.4 nozzle`
- the machine is on the network at `172.23.209.71:4408`, so Creality Print can send
  straight to it
- it is a multi-material machine. Print these single-colour — a filament change mid
  part buys nothing here and the purge wastes more PETG than the parts use.

Nothing in the design needs a specific printer; this is just what it was sized against.

## How it works

**Clamp — a collet.** The collar's nose is a cone with four slots cut down it. The
ring screws down over that cone and squeezes the slots shut onto the cane. It is a
drill chuck. Clamping force comes from a wedge, so vibration cannot walk it loose the
way it walks a snap-fit collar loose, and the grip scales with how hard you turn the
ring rather than with how well you guessed the bore.

Both thread helices run along the **print Z axis**, which is the only orientation a
printed thread is reliable in. This is why the collar is not simply a C-clamp with a
printed bolt across it: that puts the thread axis horizontal, where it prints as a
stack of overhangs.

**Aiming — pick one.** `joint = "dovetail"` (default) gives a fixed angle set when you
print the arm: stiffest, nothing to slip, but you reprint the arm to change it.
`joint = "ball"` gives a clamped ball joint — aim by hand, then screw the lock ring
down. It adds two parts (`socket`, `lock`) and reuses the same collet trick as the cane
clamp, so its holding force comes from a wedge you tighten rather than from friction.

Read this before choosing the ball: **both the hardware brief and
`../mount/DESIGN.md` rejected ball joints deliberately** — "ball joints slip under
sweep vibration and break the Point-to-Identify calibration." Clamping answers that
objection but does not delete it. An undertightened clamp still slips, and it now slips
in two axes instead of none. The dovetail arm stays the safe demo part. Run T7 (shake)
on whichever you fit and confirm the Mount card still reads 3–8° down afterwards.

**Modularity — one joint type, three interfaces.**

| Part | Is the interface to | Reprint it when |
|---|---|---|
| `collar` | the cane | the cane diameter changes |
| `arm` | the walking pose | you want a different camera angle |
| `cradle` | the phone | you change phone |
| `socket` + `lock` | the aim, if `joint = "ball"` | — |

All three meet at the same sliding dovetail running **along the cane axis**, so the
phone's weight loads every joint in shear across its widest face and never tries to
peel one open. Gravity runs within 5° of both slides, so each joint has a stop at its
lower end and something to keep it from riding back up:

- **collar ↔ arm.** With the ring off, the arm drops into the collar's socket from
  above and lands on the stop. The ring then screws on over it, and its rim reaches
  1.5 mm past the tenon's buried face: the arm can rise 0.5 mm and no more. No spring,
  nothing to click, nothing to fail. (The first design had the socket the other way up,
  held by a pawl alone against the phone's whole weight.)
- **arm ↔ cradle.** The cradle slides down onto the arm's far tenon and lands on its
  stop; a printed leaf pawl on the tenon cams in on the way and clicks out into a
  window in the cradle's roof, just below the phone's bottom edge, where a fingernail
  can push it back to release. The leaf lies on the fin's bed face, which is the only
  place a printed spring in a pocket comes out solid.

**The cradle's socket is below the phone, not behind its middle.** This is forced. The
camera has to face away from the cane, so the cradle's back plate is on the far side of
the phone from the arm, and the only route from the collar to that plate that does not go
through the phone is around its bottom edge. The arm therefore runs out and up to a pad
under the phone's bottom edge and the cradle hangs off that.

## What the app needs from any mount

From [`../README.md`](../README.md) and `../mount/DESIGN.md` — these are requirements,
not preferences, and this design inherits all of them:

- phone upright, rear camera and LiDAR clear and facing forward
- camera **3–8° below the horizon** with the cane held normally (CaneKit's Mount card
  shows it live; the trip log records it as `tilt`)
- grip firm enough that the phone's own buzz is felt in the handle
- **nothing magnetic** anywhere near the phone — the app uses the compass whenever the
  walker stands still. This design has no metal in it at all, which is the one
  requirement it satisfies for free.
- the shaft out of the camera's view

`arm_angle` is derived, not typed: `90 - cane_angle + cam_down`. Change `cane_angle`
to match how the walker actually holds it and the camera angle follows. The identity
is the one stated in `../mount/cane_mount.scad` line 33: camera pitch below the
horizon = `arm_angle + cane_angle - 90`.

`arm_reach` is load-bearing in the same way. It sets how far the phone stands off
the shaft and with it how far the shaft sits outside the camera cones: at 58 mm the lower
shaft is **47.5° off the wide camera's axis against Apple's 45° keep-out, and 5.4° outside
the LiDAR's**. Shorter is worse. The closest printed thing to the shaft is now the
cradle's dovetail block; there is an assert on that gap, it is **55 mm**, and the echo
prints it on every render.

## Measure these before you trust anything

Every one of these is currently a number someone read off a drawing or a caliper once.

- **`pole_d` — the cane. UNRESOLVED, and it is the one number everything depends on.**
  Three figures are in circulation:

  | Source | Value |
  |---|---|
  | Dial caliper, Sagar — **what this folder uses** | **27.65 mm** |
  | `1.128 in` | 28.65 mm |
  | `hardware/mount/cane_mount.scad` + the hardware brief | 28.75 mm |

  This is a 1.1 mm spread. That is not a rounding difference — it is three times any
  sane bore clearance, and a collar bored for 28.75 will simply spin on a 27.65 shaft.
  The bore coupons bracket all three — **27.75 / 28.05 / 28.35 / 28.65 / 28.95 mm**
  bores, 1–5 notches, even 0.30 steps — so the cane settles it in one **53-minute**
  print (`-Plate bore -Material PLA -Walls 4`: 52m53s, 22.4 g).

  The earlier set (27.85 / 28.25 / 28.45 / 28.95 / 29.15) was replaced because it
  *started above* the caliper reading: if 27.65 was right, the smallest ring still
  fitted and the test had no lower bracket, so it could only contradict itself. It
  also buried 28.65 and 28.75 inside one 0.50 mm gap.

  Read them with `pole_d = (smallest ring that goes on) − 0.10` — **not −0.35**, which
  is what `coupons.scad` said, and was wrong by about 0.25 mm. For a
  collet that is the difference between gripping the cane and never reaching it. Full
  procedure in [`PRINTING.md`](PRINTING.md).

  Whatever wins, **`hardware/mount/` is still modelled at 28.75 — one of the two
  folders is wrong**, so say which in `CHANGELOG.md` once you know. Measure at the
  exact spot the collar sits; canes taper.

  **Settled: 27.65 mm, by the bore rings** (ring 1 = 27.75 barely went on, 2 and 3
  went on, both colours agreed; see Step 21). 28.75 is retired everywhere. For the day a
  different shaft turns up, `.scriptsuild_stl.ps1 -PoleD 28.75` writes a collar and ring for it
  next to the 27.65 ones and `slice_gcode.ps1 -Plate collar -PoleD 28.75` slices them; only those
  two parts are sized by the cane. A closed 71 mm bore goes on over the end of the shaft - fine
  on the broom handle, not designed for a real cane with a tip and a handle (Step 21, item 4).
- **`phone_r`, `plateau_h`** — scaled off Apple's drawing, flagged MEASURE in
  `../mount/cane_mount.scad`. Same caveat here; the cradle inherits them.
- **Real clamping force.** Unknown. The collet either holds a 233 g phone through a
  full sweep or it does not, and nothing but a cane and ten minutes of walking will
  tell you.

## Known-unknown list

- Never printed as a set. Never fitted. Never walked. One ring + one collar were printed
  from the previous geometry and the ring stopped short - explained and fixed above, not
  yet re-printed.
- The pawl spring (`pawl_t` 1.2 mm, three lines) is a calculation, not a measurement:
  about 4 N to press the catch flush, 1% strain. It is on the far tenon only, and its
  pocket costs that tenon its bed-side lip over 22 of its 30 mm.
- The cradle holds the phone with bottom corner cups and two sprung top-corner caps on
  rails; the phone goes in from the front, bottom edge first, and the caps spread about
  6 mm to let the top corners past (about 2 N each, by calculation). Retention is
  positive in all six directions and needs no friction. Untested.
- The arm's dovetail tenons print on their side, so one flank of each is a 45° overhang
  and its surface is what it is; the dovetail coupon's tenons now lie the same way so the
  `dt_clear` you read off them is the one the arm gets.
- `plateau_h` (49) is still scaled off the drawing, not measured. The plate stops 2 mm
  below it; if the real plateau is lower than 47 mm from the top edge, the plate top and
  the rails' roots need to come down.
- The cane's lower shaft sits 2.5° outside the wide camera's keep-out cone at a 45° cane
  angle. A flatter walking pose puts it inside; the Mount card's tilt reading is the
  thing to watch.
- No rain hood. `../mount/DESIGN.md` wants one; this design does not have one yet.

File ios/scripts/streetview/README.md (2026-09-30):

# Street View route frames (local test input)

Google Street View captures of the ISR Townsend Hall → CIF route, one per waypoint, facing the
walking direction. They let us test the camera features without walking the route:

- `swift scripts/vision_probe.swift scripts/streetview` — what the phone's on-device Vision
  (scene labels, sign text, hazard labels) says at each corner.
- `make uitest-streetview` — the real app in the simulator uses the frame nearest to its GPS
  position as its camera (`FrameReplay`, `CANEKIT_FRAME_DIR`) and "Where am I" must answer.
- `make e2e SCENARIO=streetview` — the real app walks the whole route (simulated GPS) with these
  frames as its camera, the hazard watch on and "Where am I" asked at the start and every waypoint;
  `ios/build/e2e/report.json` lists what was said at each corner (`describes`), every text the sign
  reader saw (`scan_texts`) and every hazard-watch reply (`hazard_watch`).
- `swift scripts/sign_probe.swift scripts/streetview` — pastes a "SIDEWALK CLOSED" sign onto each
  frame at many sizes and measures how far away the app's sign reader can read it.

`frames.json` (committed) lists file, lat, lon, heading. The JPEGs are Google's imagery and are
**git-ignored**: capture them yourself — open each viewpoint in Chrome with
`https://www.google.com/maps/@?api=1&map_action=pano&viewpoint=<lat>,<lon>&heading=<heading>&pitch=-8&fov=90`,
screenshot the window at 1493×812, crop rows 185–700 (drops the Maps overlays), save as
`<file>` next to `frames.json`.

## Step 12 findings and fixes

| Found | Fix |
|---|---|
| The on-device "Where am I" template read Vision's taxonomy aloud: "Automobile, machine and vehicle in view." (Green St), "Conveyance, portal and manhole in view." (Springfield), "Furniture, table and conveyance in view." (ISR lounge) | `SceneVocabulary` (CaneKitLogic): "Ahead: the street and cars.", "Ahead: the street and a manhole cover.", "Ahead: tables, chairs and windows."; a crosswalk is said first |
| Sign range was a guess ("~5 m") | `sign_probe.swift` measured it: the old 1/80 text floor read 7.5 cm letters from ≈ 4.4 m; now 1/128 reads them from ≈ 7 m (15 cm from ≈ 14 m) on every frame, at the same OCR cost |
| At that range a STOP sign (for drivers) would be read at every stop-controlled corner | "STOP" removed from the sign phrases; "PUSH BUTTON" added |
| The e2e "passed" with no trace of the camera | trip-log `scan`, `hazard_watch`, `describe_result` records; the streetview scenario fails unless ≥ 8 of 10 corners are described |

## What the first run showed

| Where | On-device Vision saw | Notes |
|---|---|---|
| ISR lounge (start) | furniture 80 %, table 77 %, chair 52 % | indoor scene recognised |
| Goodwin / Illinois corner | crosswalk 86–95 %, road, path | crosswalk is the most reliable crossing cue |
| Green St | cars, road, traffic light (low) | |
| Springfield | manhole 98 %, road, sidewalk | |
| Mathews | sign 64 %, hydrant 16 % | hydrant present but weak |
| CIF path / entrance | sidewalk, trash can 59 %, stairs, planters | |

Text recognition read **nothing** from mid-road viewpoints (signs are ~30 px tall), so the sign
reader stayed silent the whole route — no false sign reads. On the cane, signs are metres away.
Railings score "fence" 44–62 % all along the route, which is why the on-device hazard watch only
names a label when LiDAR confirms an obstacle ahead, and is off by default.

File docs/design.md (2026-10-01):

# OpenCane design system

Visual + interaction spec for the iPhone app, the watch companion and the Live Activity.
Code twins: `ios/CaneKit/UI/Theme.swift` (phone tokens + components), `ios/CaneKitWatch/WatchTheme.swift`
(watch), `ios/CaneKit/Speech/SpeechQueue.swift` + `ios/Logic/Sources/CaneKitLogic/NavSupport.swift`
(speech rules), `ios/CaneKit/Haptics/HapticPlayer.swift` + `CueDecider.swift` (haptic patterns).

**This file describes what ships.** §5 is speech, obstacle, navigation and control cues. §6 is the
four-tab layout and the Family alerts card. §9 is the accessibility-label contract. Re-check the
Swift named in a section before you treat that section as current.

The merged safety line also audits route-time sensor changes and push-to-talk microphone failures:
`SensorModeInterlock` refuses AR session restarts while guiding, and `VoiceInputGuard` fails closed
on route, interruption, permission, and analyzer/engine errors through the existing cue channels.
Where an older spec and the Swift disagreed, the Swift won and this file changed; the parts
of the original spec that were never built are kept, marked **Not built**, so nobody "fixes" the code back
toward them by accident. From now on change a rule here and in the Swift in the same commit. Two things
outrank both: `AGENTS.md` hard rule 8 (speech priorities, §5.1) and rule 9 (accessibility labels are a
test contract, §9).

Section numbers are referenced from code comments (`§1`–`§8`, `§6.1`–`§6.8`); keep them stable.

**Added after the audit, from the code:** the hazards layer (`CaneKitLogic/Hazards.swift`,
`Depth/GroundSampler.swift`, `Scene/HazardScanner.swift`, `Scene/OnDeviceVision.swift`,
`Trip/HazardLog.swift`, `UI/HazardsCard.swift`) and `CaneKitLogic/CourseSmoother.swift` (veer
decisions) are now wired into `AppModel` / `ContentView`. Their spoken lines are in §5.1, the ground
hazard taps in §5.2, the veer rules in §5.3 and the "Hazards" card in §6 and §6.5. No test uses a
Hazards label yet (§9). The developer debug footer (`UI/DebugFooter.swift`) was removed; every mention
of it below says so.

---

## 0. Who looks at the screen, and what that forces

| Viewer | Situation | What it forces |
|---|---|---|
| **The blind user** | Never looks. Phone is clamped to the cane; they use speech, the cane's buzz, the watch, or the Action button ("Where am I"). | Every state has words: speech via `SpeechQueue`, and a VoiceOver label / value on screen. VoiceOver order is the selected tab's cards, then the tab bar (Guide / Details / Settings / Profile). Our own buttons are ≥ 60 pt (big buttons 72 pt). Nothing is colour-only. |
| **The sighted judge / teammate** | Glances at the phone on the cane from ~1 m, in a dark room (demo) or in sunlight (walk). | The Guide instruction, the distance and the depth tiles must be readable at arm's length: tile numerals 28 pt bold, hero distance 64 pt, fills ≥ 6.5:1 against their `ink` text, no thin type, no mid-grey. Dark surfaces for the demo (a bright screen in a dark room blinds the room). |
| **The developer** | Reads engine health, speech backend, watch link and the hazard detections while walking behind. | The debug cards on the **Details** tab (Hazards) and the **Settings** tab (Haptics, Watch, Mount, This phone). There is no debug footer any more (removed): depth fps is shown on the Mount card's aim row, while thermal and battery remain in the trip log's `lanes` records. |

**Brand voice.** A safety instrument, not a lifestyle app. Think avalanche beacon or aircraft
standby gauge: calm, terse, trustworthy, legible in the dark. Everything on screen is either a
measurement, a state, or a button. No marketing surfaces.

**The five rules** (the rest of this file is detail):
1. Words first. Speech is the primary channel; the screen mirrors it, never replaces it.
2. Redundancy on every hazard: a depth tile has a fill colour **and** a level word (CLEAR / FAR / NEAR /
   STOP) **and** a number; a pill is always a word on a fill (the SF Symbol is a companion).
3. Big and few. The Guide is one giant microphone (the voice tile, Step 58) with a compact row
   under it (idle: Where am I + Start route to CIF; navigating: Repeat + Next + Stop route — the one
   three-per-row exception, §6.1), then Recenter and Simulate walk below the fold; never more than
   two per row anywhere else; everything else lives in the cards below it.
4. Ivory on near-black. The white cane is the brand; the accent is *cane white on ink*, not a hue.
5. Nothing animates that carries meaning. The grid updates at 30 Hz with no transitions.

---

## 1. Typography

Fonts are system only (no bundle, no licensing, full Dynamic Type):

| Face | Used for | Why |
|---|---|---|
| **SF Pro (text design, default)** | Instructions, body, toggles, hints | Highest legibility per point at UI sizes; Dynamic Type native. |
| **SF Rounded** | Hero distance, tile metres, button labels, pills | Wider apertures and rounded terminals hold up better from 1 m and at heavy weights; it is the face Apple uses for glanceable numbers (Fitness, Watch). Only at weights ≥ semibold. |
| **SF Mono** | Nothing on screen today (the developer footer that used it was removed) | `CKFont.mono` stays defined for `accessibilityHidden` developer views. Never for user-facing text. |
| **New York** | *Not used.* | A serif has no job here. Deliberate omission, not an oversight. |
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

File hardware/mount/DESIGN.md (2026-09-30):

# Cane mount for the iPhone 17 Pro Max: design brief

Owner: Sagar (hardware, printing, CAD). App-side checks: Aritro. Written for the Sat
 demo. Files: `cane_mount.scad` (parametric model), `test_coupons.scad` (fit tests),
`pitch_model.py` (the tilt and clearance numbers in sections 4 and 5).

**Status: the SCAD files have not been rendered.** No OpenSCAD was installed where they were
written. They passed a bracket-balance and undefined-identifier check only. Press F5 before you
trust any of it.

---

## 0. Decisions

1. **Aim the camera 5° below horizontal. Keep it within 3–8°, not the 10–20° first proposed.**
   `LaneMath` splits the image into rows and never corrects for gravity. When the camera pitches
   10° or more, its torso band sees bare pavement at 1.6–2.1 m. The centre cue fires below
   2.0 m, so the cane would buzz all the time. The head band would also stop covering head
   height at the 1.5 m head-cue distance. The ground-hazard detector *is* gravity-aligned and
   still gets its near-field reference at 5° (section 4). Pitching steeper needs a software
   change first (section 13).
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

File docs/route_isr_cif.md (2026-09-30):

# Route: ISR Townsend Hall to CIF (UIUC, Urbana IL)

Waypoint file: [`ios/CaneKit/Resources/route_isr_cif.json`](../ios/CaneKit/Resources/route_isr_cif.json)
(route `name` "ISR Townsend Hall to CIF"; the JSON `recorded` field is the capture stamp). The JSON is authoritative; this page
explains it and keeps the evidence. The tables below were regenerated from that JSON.

Coordinates were pulled from OpenStreetMap; the start point was re-checked against the
University Housing ISR site plan and floor plans after the start was fixed as **Townsend Hall**. Step 10
then changed the file: WP3 became a turn (`crossing: false`), WP3 / WP6 / WP8 got 12 m
fences, WP1 got `curved: true`, every waypoint got a short `name`, and WP6 says "Turn left to face west"
before the crossing. **Not yet walked or GPS-verified**: see "To re-record on the Friday walk" below.
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

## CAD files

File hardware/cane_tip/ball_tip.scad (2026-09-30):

// =====================================================================
// OpenCane - ROLLING BALL TIP
// =====================================================================
// A printed rolling ball for the end of the shaft, so the user can feel
// the difference between a crack and a joint by rolling over it instead
// of catching in it. Zero bought hardware: no bearing, no screws. The
// commercial part this imitates (Ambutech's 2 in rolling ball) has a
// steel bearing inside; we do not, so the swivel is a printed thrust
// face and everything below follows from that one constraint.
//
// ---------------------------------------------------------------- FIT
// WHAT THIS IS FITTED TO, stated plainly because it matters:
// shaft_d defaults to 27.65 mm, which is a BROOM HANDLE. It is the
// prototype shaft, measured by the bore-ring coupons in
// hardware/mount_screwless/. It is NOT a white cane.
//
// Real long canes are much thinner, and the sources disagree with our
// prototype by a factor of two:
//   Ambutech Premium Aluminum mobility cane   13.0 mm  (0.5 in)
//   Ambutech SlimLine Graphite / Aluminum ID   9.5 mm  (3/8 in)
//   NFB Type 10 carbon fibre, tapered      15.9 -> 9.5 mm
//   NFB Type 2 fibreglass, tapered         12.7 -> 9.5 mm
//     (Rodgers & Wall Emerson, Materials Testing in Long Cane Design,
//      JVIB 99(11) 2005)
//   WHO APS24 procurement draft            "about 12mm", "13mm or smaller"
// So a real cane is 9.5-13 mm AT THE TIP END, and tapered fibre canes
// converge on 9.5. Retargeting is a 2x change, not a tweak: set shaft_d
// and RE-CHECK every derived wall, because at 9.5 mm the stem is thinner
// than the ball's lip and the failure mode moves.
//
// Broom handles do not taper, which is the one way this prototype is
// EASIER than a cane: the tip-end diameter equals the collar diameter,
// so one measurement serves both. A cane would need both measured.
//
// ------------------------------------------------------------- SAFETY
// NOT FOR STREET USE. This is a bench and demo part.
// A cane tip that comes off mid-stride is a fall, and we have no pull-off
// number to quote: there is no product standard for white canes (WHO
// APS24 points only at the general ISO 21856:2022; the FDA's 21 CFR
// 890.3075 "Cane" covers weight-bearing support canes, not long canes),
// and no manufacturer publishes a retention force. So there is no bar to
// clear and no benchmark to compare against. Any number we claim has to
// be one we measured ourselves, against a commercial tip tested the same
// way, and we have not done that.
// Both published open-source cane tips ship the same warning and tell
// users to practise indoors in a known environment first
// (github.com/MHatfull/cane_tip, MIT; printables.com/model/699705, CC0).
// Match that at minimum before this touches a pavement.
//
// Weight is a documented drawback, not a neutral trade: a COMS case
// study has a student fatiguing 20 minutes into a lesson on a 69 g
// roller ball and preferring a 39 g roller marshmallow
// (aphconnectcenter.org, "O&M: What's in a Tip?"), and Ambutech voids
// warranty on its heaviest rolling tips for thin shafts because "the
// weight of the tip could damage the cane shaft". Print this in the
// lightest infill that survives, and weigh it.
// =====================================================================

/* [What to print] */
// swivel_test FIRST - see PRINT ORDER at the bottom of this file.
part = "swivel_test"; // [swivel_test, lower, upper, stem, assembly]

/* [Shaft] */
shaft_d     = 27.65;  // mm, MEASURED. Broom handle, not a cane. See FIT.
shaft_clear = 0.35;   // mm, added to shaft DIAMETER for the slip fit.
socket_len  = 30.0;   // mm, how far the stem swallows the shaft.

/* [Ball] */
// 50.8 mm = 2 in, which is the size Ambutech's Rolling Ball Tip and
// Stationary Ball Tip both use, and the size the APH O&M textbook calls
// "the size of a billiards ball". Note this EXCEEDS the WHO APS24 draft,
// which asks for a tip "2-3cm thick" - commercial practice breaks that
// figure too, so we are following the market, not the draft. Set
// ball_d = 30 for a WHO-compliant, much lighter variant.
ball_d      = 50.8;   // mm, outside diameter of the rolling ball.
// Where the ball is split for printing, as a fraction of its DIAMETER
// measured up from the bottom pole. This is the single most important
// number in the file and it is NOT cosmetic: printed cut-face-down, the
// steepest overhang on the lower piece sits at the bed and equals
// atan(z / sqrt(R^2 - z^2)) with z = mouth_frac * ball_d - ball_d / 2.
// At 0.78 that is 34.1 deg, comfortably inside the 45 deg a 0.4 nozzle
// bridges. Lower it and the overhang worsens fast: 0.70 gives 45.6 deg,
// already past the limit. The assert below enforces it - do not just
// edit the number and hope.
mouth_frac  = 0.78;
ball_wall   = 2.40;   // mm, shell thickness of the rolling ball. 6 lines.

/* [Swivel] */
// The load path and the retention path are SEPARATED on purpose, and
// this is the whole trick of the part:
//   - the ball's weight and the user's lean ride on a SMALL radius
//     thrust boss (thrust_r). Friction torque goes as radius, so small
//     means it spins freely.
//   - the ball is HELD ON by a lip at a LARGE radius, where there is
//     room for material and the hoop stress is low.
// Doing both jobs at one radius is what makes printed swivels either
// stiff or fall apart.
thrust_r    = 5.00;   // mm, radius of the thrust boss that carries load.
thrust_gap  = 0.30;   // mm, axial running clearance at the thrust face.
lip_grab    = 1.60;   // mm, how far the retaining lip reaches inward.
lip_clear   = 0.40;   // mm, radial running clearance at the lip.
lip_slots   = 6;      // relief slots so the lip can flex over the bead.
slot_w      = 2.20;   // mm, width of each relief slot.

/* [Stem] */
stem_wall   = 3.20;   // mm, wall around the shaft socket.
bead_drop   = 1.00;   // mm, how far the retaining bead sits below the lip.

/* [Test coupon] */
// A SMALL swivel, printed first, to answer the one question that decides
// whether any of this works: does a printed thrust face and a printed
// snap lip actually spin after it comes off the bed, or does it fuse?
// Answer that on a 6 g part, not a 60 g one.
test_ball   = 25.0;   // mm, ball diameter for the swivel test coupon.
// The test coupon needs its OWN stem radius, and forgetting that was a
// real bug: stem_r comes from the 27.65 mm broom handle
// and is 17.2, so the stem measures 37.6 mm across its bead while a
// 25 mm test ball has a mouth only 21.0 mm across. The stem could not
// enter the ball it was meant to test, and the plate rendered as 2
// solids instead of 3 because the stem had merged into the cap. The
// test exists to ask "does a printed swivel spin", which needs no shaft
// bore at all - so it gets a small solid stem instead.
test_stem_r = 6.00;   // mm, stem radius on the swivel test coupon only.
test_sock   = 20.0;   // mm, stem length on the test coupon - a handle to twist.
lay_gap     = 12.0;   // mm, spacing between pieces on the test plate.

$fa = 2;
$fs = 0.6;
eps = 0.01;

// --------------------------------------------------------------- derived
shaft_r = (shaft_d + shaft_clear) / 2;
stem_r  = shaft_r + stem_wall;

// Height of the split plane relative to the ball's CENTRE (positive =
// above centre), the mouth's radius there, and the steepest overhang the
// lower piece presents when printed cut-face-down. All three are
// functions of ball diameter because the test coupon uses a smaller one.
function mouth_z(bd)  = mouth_frac * bd - bd / 2;
function mouth_r(bd)  = sqrt(pow(bd / 2, 2) - pow(mouth_z(bd), 2));
function mouth_oh(bd) = atan(mouth_z(bd) / mouth_r(bd));

assert(mouth_oh(ball_d) < 45,
       "ball split plane makes an overhang past 45 deg - raise mouth_frac");
assert(mouth_r(ball_d) > thrust_r + lip_grab + 2,
       "ball mouth is too narrow for the lip and thrust boss - raise mouth_frac");
assert(stem_r < mouth_r(ball_d) - lip_grab,
       "stem is fatter than the ball's mouth - it cannot enter the ball");
// The same check for the TEST coupon. It is a separate assert because it
// is a separate ball AND a separate stem; asserting only the real pair
// is what let the broken coupon through.
assert(test_stem_r < mouth_r(test_ball) - lip_grab,
       "test stem is fatter than the test ball's mouth - lower test_stem_r");
assert(thrust_r + 2.0 < test_ball / 2 - ball_wall,
       "thrust seat is wider than the test ball's cavity - lower thrust_r");
assert(ball_wall >= 1.6,
       "ball shell thinner than 4 lines at 0.4 nozzle - it will crush");

echo(str("ball_tip: shaft ", shaft_d, " (BROOM, not a cane)  ball ", ball_d,
         "  split overhang ", mouth_oh(ball_d), " deg  mouth r ",
         mouth_r(ball_d), "  stem r ", stem_r));
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

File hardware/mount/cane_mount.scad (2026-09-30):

// cane_mount.scad - OpenCane / CaneKit: iPhone 17 Pro Max on a 28.75 mm non-metal cane.
//
// STATUS: NOT RENDERED. Written on a machine without OpenSCAD, so nobody has pressed
// F5 on this file yet. Before printing anything:
//   1. Open in OpenSCAD 2021.01 or newer (a 2024+ development snapshot with the Manifold backend
//      renders about 100x faster). Fix any syntax error it reports (none are expected).
//   2. Set part = "assembly", press F5, and look at hinge_angle = 35, 50 and 80: the phone ghost
//      (transparent) must not touch the cane, the collar or the ear.
//   3. Select each part in turn, F6 (render), then File > Export > STL. Each part below is already
//      placed in its print orientation (see DESIGN.md section 10).
// Design brief and every number's source: hardware/mount/DESIGN.md.
// Phone numbers: Apple "iPhone 17 Pro Max - Tech Specs" (support.apple.com/en-us/125091) and
// Apple's dimensional drawing (developer.apple.com/accessories -> Dimensional Drawings,
// iphone-17-pro-max.pdf). Values marked MEASURE were scaled off that drawing or
// are not on it: check them with calipers on the real phone before the final print.
//
// Parts (set `part`):
//   collar_a  upper clamp half + ear + collar-side rosette (print standing, bore vertical)
//   collar_b  lower clamp half with M4 heat-set inserts          (print standing, bore vertical)
//   arm       cradle-side rosette + fin, screws to the back plate (print flat, teeth up)
//   cradle    back plate + side rails + bottom corner cups       (print back plate down)
//   cap       top cap that locks the phone in; 2 x M3            (print back side down)
//   knob      tool-less M5 knob (an M5 hex bolt head presses in)  (print flat)
//   assembly  everything assembled on a ghost cane, with a ghost phone (preview only)
//
// Frames used below (all right-handed, millimetres, degrees):
//   COLLAR frame: +Z = along the cane toward the grip, +Y = the "ear" direction (the upper side
//                 of the cane, where the phone stands), X = lateral (left/right of the walker).
//   PHONE frame:  +X = toward the phone's right edge as seen from the SCREEN, +Y = toward the top
//                 of the phone (Y = 0 is the bottom edge), +Z = toward the screen (Z = 0 is the
//                 back glass; the camera plateau and lenses sit at Z < 0).
//   The hinge axis is parallel to X in both frames. hinge_angle (phi) is the angle between the
//   cane axis (toward the grip) and the phone's long axis (toward its top). With the cane held
//   at cane_angle above horizontal, the camera looks (hinge_angle + cane_angle - 90) degrees
//   below horizontal. DESIGN.md section 4 explains why the target is 5 degrees, not 10-20.

/* [What to render] */
part = "assembly"; // [assembly, collar_a, collar_b, arm, cradle, cap, knob]
// Assembly only: rotate the whole thing so the cane sits at cane_angle (Y = forward, Z = up).
world_view = true;

/* [Cane] */
// MEASURED 27.65 by the bore coupons in hardware/mount_screwless/,
// and independently by dial caliper. The 28.75
// here was 1.132 in read off the wrong part of a tapered cane; a collar
// bored for it has 1.10 mm of clearance and spins on the shaft. Changed
// Do not put 28.75 back without a ring that proves it.
pole_d       = 27.65;  // mm, stick diameter at the collar spot. MEASURED.
bore_clear   = 0.3;    // mm, added to the bore DIAMETER. Retune from test_coupons.scad bore rings.
collar_len   = 44;     // mm, collar length along the cane. Keep = 2 x ear_disc_r so it prints flat.
collar_wall  = 5;      // mm, radial wall around the bore.
clamp_gap    = 1.0;    // mm, total gap between the halves as printed; tightening closes part of it.
flange_h     = 12;     // mm, clamp flange height each side of the split (Y).
clamp_bolt_z = [-13, 13]; // mm, M4 clamp bolt positions along the cane (two bolts per side).
m4_clear_d   = 4.4;    // mm, M4 clearance hole.
m4_head_d    = 7.6;    // mm, M4 socket-head counterbore diameter (head is 7.0).
m4_head_h    = 4.2;    // mm, counterbore depth (head is 4.0).
m4_insert_d  = 5.6;    // mm, hole for an M4 brass heat-set insert. CHECK your insert's datasheet.
m4_insert_len = 8.5;   // mm, insert hole depth (insert length + 0.4).
cane_angle   = 45;     // deg above horizontal, walking pose (grip 0.85-0.95 m, tip ~1 m ahead). Preview + echo only.

/* [Hinge (Hirth-style rosette, M5 bolt)] */
hinge_angle  = 50;     // deg, phi. 90 - cane_angle + 5 gives the 5-degree-down camera of DESIGN.md s4.
ear_len      = 46;     // mm, cane axis -> hinge axis (Y, collar frame). Checked for clearance at phi 35-80.
ear_t        = 10;     // mm, ear plate thickness (X).
ear_disc_r   = 22;     // mm, ear disc radius around the hinge; the angle scale is engraved in the rim.
arm_disc_r   = 19.5;   // mm, arm disc radius (smaller so the ear's scale stays visible).
teeth        = 72;     // rosette tooth count -> 360/72 = 5 degree detents. Fallback 36 (10 deg) if 72 prints mushy.
tooth_h      = 0.8;    // mm, tooth height (about a 90 degree tooth at the outer radius for 72 teeth).
rosette_r_in = 6;      // mm, inner radius of the toothed ring.
rosette_r_out = 18;    // mm, outer radius of the toothed ring.
m5_clear_d   = 5.5;    // mm, M5 clearance hole.
m5_nut_af    = 8.2;    // mm, M5 nut across flats (8.0) + 0.2.
m5_nut_h     = 4.4;    // mm, M5 nut pocket depth (nut is 4.0).
m5_head_af   = 8.1;    // mm, M5 hex bolt head across flats (8.0) + 0.1, press fit in the knob.
m5_head_h    = 3.7;    // mm, M5 hex head height (3.5) + 0.2.
knob_d       = 28;     // mm, knob diameter.
knob_h       = 10;     // mm, knob height.

/* [Arm (joins the hinge to the cradle's back plate)] */
arm_t        = 8;      // mm, arm fin thickness (X).
arm_off      = 30;     // mm, back glass -> hinge axis, measured behind the phone (phone Z).
hinge_below  = 14;     // mm, hinge axis below the phone's bottom edge (phone Y).
arm_root     = [8, 48];   // mm, phone-Y span where the fin's edge sits in the back plate pocket.
arm_screw_y  = [16, 40];  // mm, phone-Y of the two M3 screws that hold the fin to the back plate.
root_pocket  = 0.6;    // mm, depth of the locating pocket in the back plate for the fin edge.
m3_clear_d   = 3.4;    // mm, M3 clearance hole.
m3_csk_d     = 6.6;    // mm, M3 90-degree countersink diameter (flat head is 6.0).
m3_insert_d  = 4.0;    // mm, hole for an M3 brass heat-set insert (short, 5.7 mm). CHECK datasheet.
m3_insert_len = 6.0;   // mm, M3 insert hole depth.
m3_nut_af    = 5.6;    // mm, M3 nut across flats (5.5) + 0.1.
m3_nut_h     = 2.6;    // mm, M3 nut pocket depth (nut is 2.4).

/* [Phone: iPhone 17 Pro Max] */
phone_w      = 78.0;   // mm, Apple tech specs (drawing: 77.98).
phone_h      = 163.4;  // mm, Apple tech specs (drawing: 163.43).
phone_d      = 8.75;   // mm, Apple tech specs; excludes the camera plateau.
phone_r      = 11.7;   // mm, plan-view corner radius. MEASURE (drawing sheet 4 shows R11.70-R11.96 zones).
plateau_h    = 49;     // mm, camera plateau height from the top edge. MEASURE (scaled 47-49 off the drawing).
plateau_clear = 2;     // mm, gap between the plateau's lower edge and the back plate.
plateau_proud = 2.55;  // mm, back glass -> plateau surface (Apple drawing).
cam_proud    = 4.43;   // mm, back glass -> rear lens glass (2.55 + 1.88, Apple drawing).
// Rear sensors, measured from the TOP edge and from the phone's RIGHT edge (screen view) - Apple
// drawing detail D. The wide (Main) camera is "rear camera 2"; ARKit and the LiDAR depth use it.
cam_wide_from_top   = 33.61;
cam_wide_from_right = 14.37;
lidar_from_top      = 34.16;
lidar_from_right    = 64.18;
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

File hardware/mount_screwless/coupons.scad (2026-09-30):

// =====================================================================
// OpenCane screwless mount - FIT COUPONS
// =====================================================================
// Print this FIRST. It decides three numbers that every other part
// depends on. Printing the real parts before these is how you burn three
// hours and a spool finding out the bore is 0.2 mm tight.
//
// TIME, sliced, 0.4 nozzle / 0.2 layer / 4 walls / 25% gyroid:
//   what="bore"   52 m 53 s   the five rings alone
//   what="all"     3 h 01 m   the whole plate
// The header said "~25 minutes." It is not 25 minutes
// and never was; someone planning an evening around that number lost two
// and a half hours. If you only need pole_d, print what="bore".
//
// Print settings: the same profile you will use for the real parts.
// 0.4 nozzle, 0.2 layer, 4 walls, 25% gyroid, PETG. If you change the
// nozzle or the layer height afterwards, the numbers move - reprint.
//
// WHAT TO DO WITH IT
//
// 1. BORE RINGS (row 1, NOTCHED 1..5 = absolute BORE DIAMETER, mm)
//      1 notch  27.75     4 notches 28.65
//      2 notches 28.05    5 notches 28.95
//      3 notches 28.35
//    This table is the ONE thing in this header a fitter reads with parts
// in hand, and it was wrong: it still listed the
//    superseded 27.85/28.25/28.45/28.95/29.15 set while bore_tests below
//    had already moved to the values above. Every ring would have been
//    recorded as 0.10-0.20 mm larger than it is. If you edit bore_tests,
//    edit this table in the same keystroke.
//    These are bore diameters, not clearances, because the cane diameter
//    itself is disputed: the dial caliper says 27.65 mm, the repo and the
//    hardware brief say 28.75 mm, and 1.128 in (28.65) was quoted once.
//    That is a 1.1 mm spread - three times any sane clearance - so the
//    rings bracket ALL of it and the cane decides.
//
//    Slide each onto the real cane AT THE EXACT SPOT THE COLLAR SITS -
//    not up from the tip, canes taper. Record the whole pattern ("1,2,3
//    will not go; 4 goes firm; 5 rattles"), not just the winner. Then:
//      pole_d = (the SMALLEST ring that goes on at all) - 0.10
//    NOT minus 0.35. A rigid 10 mm ring that goes on with firm thumb
//    pressure has about 0.05-0.15 mm of clearance on diameter, not 0.35,
//    so the old formula came out ~0.25 mm small and a collet bored that
//    tight will not reach the cane at all before the nut bottoms out.
//    If you printed these in PLA and the collar will be PETG, subtract a
//    further 0.06 mm - or just take the larger ring when you are borderline.
//
//    bore_clear is NOT an output of this test. These rings are rigid; the
//    collar is a collet that closes. Set bore_clear as a design decision
//    (0.40 today) and let collet_squeeze take it up.
//
// RESULT — this test has been RUN and it is settled:
//      1 notch  27.75  barely went on   <- the bound
//      2 notches 28.05  decent
//      3 notches 28.35  decent, yellow and white agreed
//    pole_d = 27.75 - 0.10 = 27.65, matching the dial caliper exactly.
//    hardware/mount/'s 28.75 was wrong by 1.10 mm and is retired.
//    You do not need to reprint these rings unless the cane changes.
//
// 2. THREAD ROW (row 2): ONE stub + FOUR fluted nuts.
//      stub  = threads on the OUTSIDE, sits on a thin flange
//      nut   = 10 scallops round the rim, thread hidden INSIDE
//
//    NOTCHES ON THE NUT'S TOP RIM -> [thr_clear, thr_axial], mm:
//      1 notch   0.45  0.25     radial step only
//      2 notches 0.35  0.45     AXIAL step only
//      3 notches 0.45  0.45     both, modest
//      4 notches 0.55  0.65     both, generous
//    TWO numbers per nut, not one. This table was written for an earlier
//    THREE-nut set stepping thr_clear 0.35/0.45/0.55 and was not updated
// when the set became four pairs — it would have named
//    the wrong clearance for every nut on the plate. Read it from
//    thr_tests below, and if you edit thr_tests, edit this in the same
//    keystroke. It is the same defect this file's bore table carried,
//    and the reason that one now has a warning attached to it.
//
//    Screw each nut down the stub by hand, no tool. Take the SMALLEST
//    nut that turns freely for the WHOLE length. Put both its numbers in
//    `thr_clear` / `thr_axial`. Expect some rocking play at the top - up to
//    about 1 mm on nut 3 - and do not count it against the nut: with the
//    60-degree flanks the radial clearance turns into axial slack too
//    (0.45 radial adds 0.26 per flank), and it all disappears once the
//    real ring bears on the collet's cone. Free running is the test.
//
// WHY TWO AXES. The bench run had one nut, [0.35, 0.25],
//    and it went down two turns of four and then jammed. That rules out
//    both single-axis causes: not radial clearance, because the first
//    two turns were free; not elephant's foot on the stub, because that
//    binds at the LAST turn against the flange. Binding that worsens as
//    more teeth engage is cumulative per-tooth error, and the clearance
//    that absorbs it is axial - thr_axial was 0.25 mm, 1.25 layers at
//    0.2 mm. Two teeth can wiggle into alignment; four cannot.
//    So nut 1 tests the radial theory, nut 2 the axial one, and which
//    of them frees the thread is the answer.
//    If ONLY nut 4 works, stop and investigate - a loose thread is
//    hiding a fault, not fixing one.
//
//    WHERE it binds, note it either way:
//      tight from the first turn       -> radial. Nut 1 or 3.
//      free, then jams part-way down   -> axial. Nut 2 or 3.
//      free, then jams AT THE FLANGE   -> elephant's foot on the stub's
//        first layers, not clearance at all. Chamfer the stub; do not
//        open the thread to paper over it.
//
// 3. DOVETAIL PAIR (row 3, NOTCHED 1/2/3 = 0.15/0.25/0.35 clearance)
//    Slide each tenon into its socket. You want it to slide with thumb
//    pressure and stay put when you shake it. Put that number in
//    `dt_clear`. The tenons lie on their side with the width vertical,
//    the way the arm's tenons print, so the lower flank (a 45-degree
//    overhang) is in the measurement. Judge the fit with the tenon's
//    notched base face DOWN, i.e. in the orientation it was printed.
// (Flanks were 67 degrees: they printed in
//    air on the arm and the slicer put support inside the cradle's socket.)
//
// Coupons are identified by NOTCHES, not printed numbers: count the
// notches in the rim, fewest = smallest clearance. Notches are used
// because OpenSCAD's text() needs fontconfig, which the portable Windows
// snapshot does not ship - text() there renders as nothing at all and you
// get four identical unlabelled rings. Notches also read by thumb, which
// matters on this project.
//
// Write the three numbers on the coupon with a paint pen when you are
// done, and tell the next person. They are cane- and printer-specific.
// =====================================================================

/* [What to print] */
what = "all"; // [all, next, bore, thread, dovetail]
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

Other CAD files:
hardware/mount_screwless/screwless_mount.scad
cad/chest_plate.scad
cad/grip_module.scad
cad/sensor_pod.scad
hardware/mount/test_coupons.scad
hardware/mount_screwless/verify.scad

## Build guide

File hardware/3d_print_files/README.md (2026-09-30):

# 3D print files — the screwless phone mount

**G-code and STLs are not in git.** They are build artifacts (~85 MB of sliced jobs). Generate
them locally on a Windows machine with OpenSCAD and Creality Print, then copy the output here
for the printer room. The `.scad` sources in [`../mount_screwless/`](../mount_screwless/) are
the source of truth.

```powershell
# From the repo root on Windows (OpenSCAD + Creality Print installed):
.\scripts\verify_mount.ps1          # clearance / mechanism checks — all green before slicing
.\scripts\build_stl.ps1             # → hardware/mount_screwless/stl/
.\scripts\slice_gcode.ps1           # → hardware/mount_screwless/gcode/
# Copy what you need into this folder for the USB stick:
Copy-Item hardware\mount_screwless\gcode\*.gcode hardware\3d_print_files\gcode\
Copy-Item hardware\mount_screwless\stl\*.stl hardware\3d_print_files\stl\
```

After a `git pull`, run those three commands (or copy from whoever last sliced). The design,
the reasoning and the full operator runbook are in [`../mount_screwless/PRINTING.md`](../mount_screwless/PRINTING.md);
this page is only *what to print* once the files exist locally.

**The G-code carries its own temperatures.** The filament slot you pick on the touchscreen only
decides which plastic gets fed to them. Check the Filament Selection screen before every job.
If it shows `PETG -> [blank]`, that machine has no PETG — do not map it onto a PLA slot.

| Material | Nozzle | Bed | Slot on the room's machines (check!) |
|---|---|---|---|
| PLA | 220 °C | 55 °C | 3 or 4 |
| PETG | 250 °C | 80 °C | 2 |

## Print in this order

Do not skip step 1 — three clearances in it are printer-specific and every part depends on
them. The bore rings are **already done** (`pole_d` = 27.65 mm, measured ); their
files are generated for completeness only.

| # | Job (in local `gcode/`) | Slot | ≈ Time | Then |
|---|---|---|---|---|
| 1 | `PETG_slot2__next_*` | PETG | 3 h 33 | Thread row + dovetail row in one job. Read it — below. On two machines: `PETG_slot2__thread_*` (2 h 24) + `PLA_slot3or4__dovetail_*` (42 min) |
| 2 | `PETG_slot2__arm_*` | PETG | 39 min | Needs no coupon. Any free machine, any time |
| 3 | `PETG_slot2__collar_*` | PETG | 1 h 43 | After step 1 is read |
| 4 | `PETG_slot2__ring_*` | PETG | 55 min | Same |
| 5 | `PETG_slot2__cradle_*` | PETG | 1 h 34 | Prints with support under the back plate. Peel it off; nothing touches that face |

Flat on the bed as sliced. Rotate nothing.

## Reading step 1

**Thread row — one threaded stub, four fluted nuts, notched on the top rim.** Screw each nut
down the stub by hand. Take the **smallest nut that runs freely for the whole length**. A loose
nut rocks about 1 mm at the top — normal, not a fault.

| Notches | `thr_clear` | `thr_axial` | |
|---|---|---|---|
| 1 | 0.45 | 0.25 | |
| 2 | 0.35 | 0.45 | |
| 3 | 0.45 | 0.45 | **the collar and ring are cut to this one** |
| 4 | 0.55 | 0.65 | if only this one works, something else is wrong — say so |

**Dovetail row — three tenons, three sockets, notched 1 / 2 / 3.** Notched base face **down**,
the way it printed. Slide each tenon into its socket; you want the one that moves with thumb
pressure and stays put when shaken.

| Notches | `dt_clear` | |
|---|---|---|
| 1 | 0.15 | |
| 2 | 0.25 | **the parts are cut to this one** |
| 3 | 0.35 | |

If the winners are **nut 3 and dovetail 2, print steps 3–5 as they are.** If not, write the
numbers on the coupon with a paint pen and tell whoever has the Windows machine: they go into
`hardware/mount_screwless/screwless_mount.scad` (`thr_clear`, `thr_axial`, `dt_clear`), then
`scripts\verify_mount.ps1`, `scripts\build_stl.ps1`, `scripts\slice_gcode.ps1` — five minutes —
and the new files get copied back here.

## Putting it together

1. **Ring off.** Drop the arm into the collar's socket from the top until it lands on the stop.
   Screw the ring on over it. The ring is the lock; there is no catch on this joint.
2. Slide the cradle **down** onto the arm's far tenon until it stops. The leaf catch clicks into
   the little window just under where the phone's bottom edge sits. Fingernail through that
   window to release.
3. Phone in from the **front**: bottom edge into the two corner cups first, then press the top
   back until the two corner caps snap over the top corners. To take it out: spread the two
   rails with a thumb and finger, lift the top edge.
4. On the cane: collar on, slide it to where it goes, tighten the ring.

**Pass/fail at the collar:** with **no cane** in it the ring reaches the shoulder. With the
**cane in** it stops about 3 mm short — that is the clamp gripping. If it reaches the shoulder
with the cane in, the bore is too big for that shaft.

## Not settled yet

- The three coupon numbers — step 1 decides. The parts are cut to the expected winners.
- The camera plateau height (`plateau_h` = 49 mm) is scaled off Apple's drawing. Measure it with
  calipers while the phone is out; if it is under 47 mm, say so before the cradle is printed.
- The prototype shaft is a **broom handle** (27.65 mm). A real long cane is 9.5–13 mm at the tip
  and has a tip and a handle; this collar is a closed bore and goes on over the end. Later.
- Nothing from this geometry has been printed yet. The model checks are all green
  (`scripts\verify_mount.ps1`); the printer has the last word.

## Expected local files

After `build_stl.ps1` + `slice_gcode.ps1`, `gcode/` should contain jobs like:

| pattern | material, slot | what |
|---|---|---|
| `PETG_slot2__next_*` | PETG, 2 | fit coupons: thread stub + 4 nuts, 3 dovetail pairs |
| `PETG_slot2__thread_*` | PETG, 2 | the thread row alone |
| `PLA_slot3or4__dovetail_*` | PLA, 3/4 | the dovetail row alone |
| `PETG_slot2__arm_*` | PETG, 2 | arm |
| `PETG_slot2__collar_*` | PETG, 2 | collar (the cane clamp body) |
| `PETG_slot2__ring_*` | PETG, 2 | ring (the clamp nut) |
| `PETG_slot2__cradle_*` | PETG, 2 | cradle (the phone holder), support on |

`stl/` has the same parts plus `coupons_bore.stl` (done, not needed again), already in print
orientation — do not rotate them in a slicer. The cradle needs support on build plate only,
with bridges left unsupported so its dovetail socket stays empty. Nothing else needs support.

File names carry the print time (`_1h43m27s`), so a stale slice is easy to spot after a
`.scad` change.

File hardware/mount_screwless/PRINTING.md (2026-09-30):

# Printing the screwless mount — operator runbook

## Print list — read this if you are standing at a printer

The G-code and STLs are **not in git** (~85 MB of build output). Generate them with the five
commands under "Slicing" below, copy into [`hardware/3d_print_files/`](../3d_print_files/), then
check the Filament Selection screen before every job.

| # | File | Slot | Time | Then |
|---|---|---|---|---|
| ~~0~~ | bore rings | — | — | **Done.** `pole_d` = 27.65 mm . Do not reprint |
| 1 | `PETG_slot2__next_*.gcode` | PETG | 3 h 33 | Thread row + dovetail row. Read it — "Reading the thread set" and "Reading the dovetail pair" below. On two machines: `PETG_slot2__thread_*` (2 h 24) + `PLA_slot3or4__dovetail_*` (42 min) |
| 2 | `PETG_slot2__arm_*.gcode` | PETG | 39 min | Needs no coupon. Any free machine, any time |
| 3 | `PETG_slot2__collar_*.gcode` | PETG | 1 h 43 | After step 1 is read. Cut to thread nut 3 and dovetail 2; if other coupons win, put their numbers in `screwless_mount.scad`, run `verify_mount.ps1`, rebuild, re-slice |
| 4 | `PETG_slot2__ring_*.gcode` | PETG | 55 min | Same |
| 5 | `PETG_slot2__cradle_*.gcode` | PETG | 1 h 34 | Prints with support under the back plate; peel it off |

Flat on the bed as sliced; rotate nothing. Assembly is under "Fitting it together". The
pass/fail at the collar: **no cane in, the ring reaches the shoulder; cane in, it stops ~3 mm
short.** Not settled: the three coupon numbers (step 1), `plateau_h` (measure the camera
plateau's height from the top edge with calipers while the phone is out), and the fact that the
prototype shaft is a broom handle — nothing from this geometry has been printed yet.

This is the how-to. [`README.md`](README.md) is the why. If you are standing at a
printer and want to know which file to send, you are in the right document.

Everything here was established on the night of on the SPARKX i7s in the
room, mostly by getting it wrong first. Where a number came from a measurement it says
so; where it is still a guess it says that too.

## The one rule

**A G-code file carries its own temperatures. You cannot fix a wrong one at the printer.**

Creality's machine profile substitutes the numbers into the start macro at *slice* time:

```
START_PRINT EXTRUDER_TEMP=220 BED_TEMP=55
```

That line is frozen into the file. Re-tagging the spool on the touchscreen does not
change it. All the filament-slot choice decides is *which plastic gets fed to that
temperature* — and nothing on the machine checks that the two agree.

So a PETG plate sent to a printer whose CFS holds four PLA spools will heat to 250 °C
and push PLA through it: stringing, ooze, a likely heat-creep jam, and a first layer
squashed soft on an 80 °C bed. That nearly happened here. The tell is on the Filament
Selection screen — the job chip reads

```
PETG  ->  [blank]
```

and that blank means the machine has nothing to satisfy it. **Back out. Do not map it
onto a PLA slot.**

| Material | Nozzle | Bed | Slot, on the machines in this room |
|---|---|---|---|
| PLA | 220 °C | 55 °C | 3 or 4 |
| PETG | 250 °C | 80 °C | 2 |

The slot numbers are *not* a property of the design — they are where the spools happened
to be. One machine in the room has PLA in all four. Check the screen every time, and set
the slot by hand rather than tapping AUTO so you can see which spool it picked.

## Slicing

```powershell
.\scripts\verify_mount.ps1                                 # 30 model checks, ~2 min. Green before anything else.
.\scripts\build_stl.ps1                                    # .scad -> stl/   (add -PoleD 28.75 for the other cane)
.\scripts\slice_gcode.ps1 -Plate bore -Material PLA -Walls 4   # stl -> gcode/
```

`build_stl.ps1` writes every part, including the three single-row coupon plates the slicer
asks for by name (it did not, once, and the first command in this file failed on a fresh
clone). `-PoleD 28.75` adds a collar and ring for that cane next to the 27.65 ones; nothing
else is sized by the cane.

**Support is the slicer script's job, not yours.** The vendor profile has it off and the
command line does not turn it on; the first headless cradle file went out with
`enable_support = 0` and would have printed its back plate in mid-air. `slice_gcode.ps1` now
turns it on for the cradle (build-plate only, bridges left alone so the dovetail socket
stays empty) and refuses to write a cradle file without it. It prints a `support` line
in its verification block; read it.

`slice_gcode.ps1` drives Creality Print 7.2 headlessly — it is an Orca fork and takes
Orca's command line, so no GUI, no fighting for the mouse, and the same inputs give the
same file every time. It re-opens what it wrote and prints the material, both
temperatures, the wall count, the time and the weight, and it **refuses to name a file
safe if it cannot read the material back out**. Read that block before you print.

G-code lands in `hardware/mount_screwless/gcode/`, which is gitignored like `stl/`.

Two Windows gotchas are baked into that script with comments explaining them. Do not
tidy either away:

- The Creality exe needs `2>&1 | Out-String` **and** a relaxed `$ErrorActionPreference`.
  It logs its whole run to stderr at `[error]` level even on success; unredirected under
  `-ErrorAction Stop` the call returns instantly with an empty exit code and writes no
  G-code, which looks exactly like "the model does not fit the bed".
- This is the **opposite** of `build_stl.ps1`, where `2>&1` must be *avoided* because it
  trips `$?` on OpenSCAD's clean exits. Same shell, same version, opposite fix — the two
  executables use the streams differently.

Orca writes its settings block as a **footer**, roughly 600 to 36 lines before EOF, not
a header. Reading only the head of the file gets you the `START_PRINT` line and nothing
else.

## Print order

The cane's diameter gates everything. `collar`, `ring`, `cradle` and `socket` all derive
from `pole_d`, so none of them can be sliced honestly until the bore rings have been read.

| # | Plate | Material | Time | What it settles |
|---|---|---|---|---|
| ~~1~~ | ~~`-Plate bore -Walls 4`~~ | PLA | 52m48s, 22.4 g | **DONE : `pole_d` = 27.65.** Do not reprint unless the shaft changes |
| 2 | `-Plate next -Walls 4` | PETG | 3h33m, 54.3 g | `thr_clear`/`thr_axial` (stub + four nuts) **and** `dt_clear` (three dovetail pairs) in one job |
| 2a | `-Plate thread -Walls 4` | PETG | 2h24m, 31.8 g | the thread row alone, if you only want that |
| 2b | `-Plate dovetail` | PLA | 41m57s, 15.2 g | the dovetail row alone |
| 3 | `-Plate arm` | PETG | 38m55s, 16.0 g | nothing — it is a real part and needs no coupon, see below |
| 4 | `-Plate collar` + `-Plate ring` | PETG | 1h43m + 55m, 23.1 + 15.1 g | the clamp, cut to nut 3 [0.45, 0.45]; rebuild if a different nut wins |
| 5 | `-Plate cradle` | PETG | 1h34m, 33.3 g (support on) | the phone holder |

The gcode for every row is in `hardware/mount_screwless/gcode/` as of (late),
named by material, slot, plate and time. The thread row's time doubled against the earlier
two-ring plate because it is now the four-nut bracket from Step 21.

**The arm is the exception and it is worth knowing why.** It is the only real part that
can be printed before any measurement comes back. Its tenons are drawn at
`dt_section(0)` — nominal, no clearance applied — and the pawl is fixed geometry, so
neither `pole_d` nor `dt_clear` reaches it. Print it whenever a machine is free.

## Reading the bore rings

Before anything else, spend 60 seconds with the caliper at the exact spot the collar will
sit, three times, rotating 120° between readings. The two figures in dispute are **27.65**
and **28.65 mm** — exactly 1.00 mm apart, which is the signature of a digit slip rather
than two honest disagreeing measurements. If three readings agree, you do not need the
print.

Rings are identified by **notches**, fewest = smallest:

| Notches | Bore |
|---|---|
| 1 | 27.75 mm |
| 2 | 28.05 mm |
| 3 | 28.35 mm |
| 4 | 28.65 mm |
| 5 | 28.95 mm |

Slide each onto the cane **at the collar station** — not up from the tip, canes taper.
Record the whole pattern ("1,2 will not go; 3 goes firm; 4,5 rattle"), not just the
winner; the pattern is what shows the reading is real. A ring that hangs up in the first
millimetre and then slides free is first-layer squish, not the bore — judge at mid-height.

Then:

```
pole_d = (the SMALLEST ring that goes on at all) - 0.10
```

**Not −0.35.** The older note in `coupons.scad` said 0.35 and was wrong by about 0.25 mm.
For a collet that is the difference between gripping the cane and never reaching it.

Print the rings at **4 walls**. At the profile default of 2, a 10 mm ring is 1.7 mm of
solid over 2.5 mm of 15% grid — it flexes under your thumb, so a bore that is genuinely
too tight still feels like it "goes on" and the gauge reads large.

`bore_clear` is **not** an output of this test. The rings are rigid; the collar is a
collet that closes onto the cane when you tighten the nut. Clearance there is a design
decision (0.40 today) and `collet_squeeze` takes it up.

### Why both a PLA and a PETG ring set

The collar will be PETG. PETG shrinks more than PLA — the estimate is ~0.06 mm on a
28 mm bore, worst case 0.168 mm, and that worst case is larger than the clearance the
collet has to work with. It is the weakest link in the whole measurement. A PETG ring set
removes it: you measure with rings made of the material the real part will be made of.

If you have both, **use the PETG answer.** If you only have PLA and you are borderline
between two rings, take the larger one.

## Reading the thread set

One stub, **four** nuts, notched on the top rim. Each nut is a pair [radial, axial]:

| Notches | `thr_clear` | `thr_axial` | what it tests |
|---|---|---|---|
| 1 | 0.45 | 0.25 | radial step only |
| 2 | 0.35 | 0.45 | axial step only |
| 3 | 0.45 | 0.45 | both, modest — **the collar and ring are cut to this one** |
| 4 | 0.55 | 0.65 | both, generous — if only this one works, something else is wrong |

Screw each down the stub by hand, no tool. Take the **smallest nut that runs freely for the
whole length** and put both its numbers in `thr_clear` / `thr_axial`, then rebuild the
collar and ring if it is not nut 3. **Rocking play at the top is not a fault**: with 60° flanks
the radial clearance turns into axial slack as well (about 0.49 mm per flank on nut 3), so a
loose nut rocks about a millimetre. It vanishes the moment the real ring bears on the cone.
Where it binds tells you what is wrong: tight from the first turn → radial; free then jams
part-way → axial; jams only at the flange → elephant's foot on the stub's first layers.

**What "fully down" means on the real collar.** With no cane in it, the ring runs all the
way to the shoulder; the last two and a half turns get stiff as its cone closes the collet
fingers (0.6 mm radial, by design). **With the cane in, the ring stops about 3 mm short of
the shoulder.** That is the clamp: the fingers have met the cane and the rest of the
travel is preload. A ring that reaches the shoulder with the cane in means the bore is too
big for that cane. A ring that stops more than ~5 mm short with the cane *out* is binding,
and the thread set above is how you find out why.

This is the coupon that matters most right now. Until the thread generator
produced no thread at all: a twisted `linear_extrude` maps **angle** to height, and the
tooth was drawn as a flat offset in y, so it came out **0.031 mm** thick and sliced away
to a smooth cylinder. The collar's "clamp" was a plain tube. It measures 0.62–0.75 mm
now, and this coupon is the first physical proof either way.

**If the ring will not thread on, do not print the collar.**

Prefer the PETG result — `thr_clear` is material-dependent and the collar is PETG.

## Reading the dovetail pair

Notched 1/2/3 = 0.15 / 0.25 / 0.35 mm. Slide each tenon into its socket: it should move
with thumb pressure and stay put when you shake it. That number goes in `dt_clear`.

The tenons lie on their side, notched base down, exactly as the arm's tenons print: the
dovetail's width is the build axis, so one flank is a 45° overhang and its finish is part
of the number. Test them the way they were printed, base face down. (A tenon printed
standing up has perfect flanks and reads a clearance the arm never gets.)

## Fitting it together

1. **Ring off.** Drop the arm into the collar's socket from the top - its tenon clears
   the threaded band on the way down - until it lands on the stop 5.5 mm above the
   collar's base. Then screw the ring on. The ring's rim now sits over the tenon and the
   arm cannot come out. There is no pawl on this joint; the ring is the lock.
2. **Slide the cradle down onto the arm's far tenon** from above until it stops. The leaf
   pawl on the tenon cams in on the way and clicks out into the window in the cradle's
   roof, just below where the phone's bottom edge will sit. To release, press the catch
   back through that window with a fingernail and lift.
3. **Phone in from the front:** bottom edge into the two corner cups first, then press
   the top back until the two corner caps snap over the top corners. They spread about
   6 mm to let the corners past. To take it out, spread the two rails with a thumb and
   finger and lift the top edge clear. The floor between the cups is open for the USB-C
   plug, the speaker and the mics.
4. **On the cane:** collar on with the ring loose, slide it to station, tighten the ring
   until it stops. See "what fully down means" above.

The socket and the real part are built by the same method, so the number transfers even
though the clearance is not perfectly uniform around the flank — see the known-issue list
in `README.md`.

## Calibration

- **Bed mesh: yes**, worth the two minutes. Ring 1 and ring 5 sit 182 mm apart, so bed
  tilt reads as a fake difference in bore size.
- **Input shaping and flow calibration: no**, not before a gauge print — they run at job
  temperature and cost time.
- Whatever calibration state you print the coupons in, **print the collar in the same
  state**. The point of a gauge is that it and the part share their errors.

## Getting files onto a machine

These printers were not reachable over the LAN from the dev laptop (`172.23.209.71:4408`
refused), so it was USB the whole night.

- A printer's file browser gets slow with a few hundred loose files on the stick. Putting
  everything else in one subfolder fixes it — the browser only lists the root.
- **Do not assume you can pull the stick out once a print starts.** Whether the machine
  streams from USB or copies to internal storage was never confirmed on these units. If
  you need the stick for a second printer, check the touchscreen for a "copy to local"
  option first; failing that, start the print, let it lay real plastic for two minutes,
  then pull it — if it stops you have lost two minutes instead of an hour.

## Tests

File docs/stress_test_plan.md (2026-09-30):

# OpenCane stress test and end-to-end test plan

Written against the hazards layer, the Files app keys and the review fixes, then re-checked
once those were in the tree. Every number here comes from the code: `CaneKitLogic`
defaults, `NavigationEngine`, `SpeechQueue`, `BeaconEngine` and `route_isr_cif.json`. If the code
and another doc disagree, the code is right; §0 lists the disagreements. If a number in the code
changes, update this file.

**Re-checked after Step 37** against `SpeechQueue`, `SpeechResume`,
`CueRules`, `TorchSwitch`, `DualCameraRotation`, `FaceTrackingChange`, `ios/scripts/cue_audit.py` and
CHANGELOG Steps 34–37: §0.12, §1.0–§1.4, D7, D8, D15 changed, and **D19–D24** are new (flashlight
settle, both cameras refusal + rotation, face-tracking refusal, cue level × place, talk-floor resume +
pause, reading `make audit`).

**People.** **Aritro**, **Aarav** and **Tejas** do the software: builds, automation, logs, phone
setup, filming. **Sagar** and **Tommy** do the hardware: clamp, mount angle, cane, power bank, sun
shade, heat. On the walks **Aarav** is the walker and wears the watch and AirPods. For the
blindfolded walks, Sagar spots and Aritro films.

**Test IDs.** A = automated · B = bench (indoors, phone plugged in) · W = outdoor walk ·
D = device matrix (§2) · F = failure injection (§3) · G = go/no-go (§4).

---

## 0. Read this before testing: facts from the code that change how you test

1. **The trip log and the hazard map are in the Files app.** `ios/project.yml` sets
   `UIFileSharingEnabled` and `LSSupportsOpeningDocumentsInPlace` to `true`, so Documents shows up
   under **Files → On My iPhone → OpenCane**: the trip logs `canekit-*.jsonl` and
   `hazards/hazards-<session>.geojson` with its photos. AirDrop them from there after every walk; the
   Mac (§1.4) is only the fallback. A phone still running a build from before that change needs one
   `make run` first.
2. **A screen lock stops obstacle sensing and says nothing.** A lock sends the app to the
   background, which pauses ARKit and stops the haptics. GPS, speech, the beacon and watch cues keep
   running (the `location` and `audio` background modes). Guided Access with the side button disabled
   is required (D16).
3. **A killed app doesn't resume the route.** "Start route to CIF" starts again at WP1. Look-ahead is
   only 2 waypoints and passed-by needs you within 2 × radius, so from mid-route the tracker is stuck
   and the beacon points back toward ISR. The recovery is to press **Next** once per waypoint already
   passed (F12 table).
4. **Some things are not in the log.** Heading, bearing error, beacon volume, head yaw, which voice
   played (ElevenLabs or System), fps, AR tracking state, the channel lines spoken at route start,
   connect and disconnect lines (only an `audioroute` event), "Describing." and the description text.
   For those, screen-record (Control Center) or film the Guide and Haptics pills.
5. **WP1's line is spoken twice.** The intro ("Route started. … First: Leaving Townsend Hall…") says
   it once, and entering the WP1 fence says it again as soon as you move faster than 0.5 m/s. This is
   expected.
6. **WP8 gets no wrist tap.** Its line says "Turn left", but the bearing only changes 265.0° →
   237.4° = −27.6°, and the turn tap needs more than 30°. This is expected (e2e `clean` asserts it).
   The WP1→WP2 leg is `curved`, so the beacon is silent and there are no veer cues until WP2.
7. **Head yaw is ignored until a Recenter.** After route start, each waypoint and each AirPods
   reconnect, the beacon uses the phone heading alone until a manual Recenter or an auto-recenter.
   The auto-recenter (`StraightWalkDetector`) needs 3 consecutive fixes (the first counts) at
   **> 0.6 m/s**, accuracy ≤ 20 m, course steady within 15° from fix to fix, head yaw within 8° from
   fix to fix, AirPods head tracking live, no turn still settling, and ≥ 15 m past a just-reached
   crossing. Any failed check starts the count again; it never fires on a timer. The head-turn check
   in `devices_setup.md` only works after you press Recenter.
8. **Heat handling is thinner than the docs say.** `.serious` or `.critical` turns mesh
   classification off (so no obstacle names), pauses sign reading and the hazard watch, and freezes
   the live camera view. "Phone is hot. Door and wall names and sign reading paused." is spoken
   once when it turns hot; lanes and haptics keep running, and at `.critical` the beacon stays on. There's no low-battery
   line. The debug footer is gone: thermal, battery, camera tilt (`tilt`) and depth rate (`fps`) are
   in every `lanes` log record, and the Mount card shows "Camera tilt N° down · N fps" live; on the
   walk, listen for the hot line.
9. **Arrival gate.** The fix must satisfy `distance + accuracy/2 ≤ 20 m` (WP9 radius) on 2
   consecutive fixes with accuracy ≤ 30 m, and there's no speed gate. So at ±10 m accuracy, arrival
   fires within 15 m of the node. Intermediate fences need accuracy ≤ 20 m and speed > 0.5 m/s. Speed
   is −1 when standing, which fails the gate.
10. **`docs/route_isr_cif.md` matches the JSON** (its tables were regenerated from that JSON): WP3, WP6 and WP8 are 12 m, WP9 is 20 m, and WP3 is **not** a crossing. Crossings are
    WP4, WP6 and WP7. If the two ever disagree, the JSON is the truth.
11. **Watch and cane haptics** (`WatchModel`, `HapticPlayer`; design.md §5.3 / §6.6 agree). Wrist:
    turnLeft `.directionUp`, turnRight `.directionDown`, crossing `.notification`, arrived `.success`,
    and mirrored obstacles left `.start` / right `.stop` / center `.click` / head `.failure`. A button
    press that can't reach the phone plays `.retry`. Every route cue (and veer) is also felt on the
    cane as soft continuous buzzes: left one 0.45 s buzz, right two 0.35 s, crossing three 0.3 s,
    arrived long-short-long. A ground hazard is 4 heavy taps.
12. **Voice cache.** At launch the app prefetches `AppModel.commonLines`: the fixed strings plus `CueRules.allSpokenLines`, `TorchSwitch.allSpokenLines`, `SpokenPhrases.shellLines`, `LowLightAdvice.allSpokenLines` and `RouteStatusLines.allSpokenLines`. At route start it prefetches the 9 waypoint `say`
    lines, `commonLines` again and the intro, then `SpokenPhrases.warningLines` (74 generated warning
    lines) as a background tail; 2 requests are in flight at a time (`VoicePrefetch.maxConcurrent`).
    Any line built at runtime is a cache miss: Repeat (it includes a distance), "Passed X. Y in N
    meters.", the arrival summary, "\<AirPods\> connected.", channel warnings. A describe already in flight plays `Earcon.busy`, not a spoken "Describing.". A route
    or Repeat line that misses waits up to **2.5 s** for ElevenLabs, then falls back to the system
    voice (and for 60 s after such a failure every miss goes straight to the system voice). Obstacle
    and safety lines never wait.
13. **A cut line resumes, it does not restart (Step 37).** When "Head height." (or any higher band)
    cuts a line, the line continues from the start of the clause it was cut in, after a 0.35 s pause
    — not from its first word. A cut inside the first clause resumes from the top; after a phone call /
    Siri or dictation the line restarts from its last resume point (the top if it was never cut). A line is resumed at most 3 times, then dropped: press
    Repeat. The trip log shows it as `speech_dispatch {replays ≥ 1, resume_from > 0}` (D23).
14. **Speak obstacle names is off by default (Step 36)** and the Cues card decides which names and
    signs are spoken (Quiet / Indoors: no names, safety signs only). D6 and D22 turn names on first;
    every other test runs on the default Detailed + Outdoors. Check the `start` record's
    `cue_level`, `cue_place`, `obstacle_names` before comparing two walks.

---

## 1. Test levels

### 1.0 The next 24 hours

| Block | When | What runs | Who | Done when |
|---|---|---|---|---|
| A: bench | Tonight, phone plugged in, ISR lobby, ~4.5 h | A1–A5, A7; **D18 first** (needs a fresh install); D1–D8, D10, D11, D13, D15–D17, **D19–D23**; F10, F11, F12 drill | Aritro on all; Sagar D1–D5 + D16 clamp; Aarav D2, D11 | Every bench D-test passes, or is on the bug list with its log file |
| B: first daylight | Sat from ~08:00 (sunrise ≈ 06:35 CDT), ~2 h | W1 survey → route JSON fixes → A1 + A5 → reinstall + B-smoke → **W2 reference walk** (D9, D12, D13, D14) → **D24** (`make audit` on the W2 log) | Aarav walks, Aritro logs and films, Sagar spots | W2 meets every D12 pass criterion and D24 reads ON THE MOUNT |
| C: stress | 11:00–14:00 | W3 stress walk ≥ 30 min (F1–F3, F5–F9, F12); F4 at 12:30–13:30 | All three | Every F result logged |
| D: fix + freeze | After C, ~2 h | Triage logs → fixes → A1–A6 → reinstall → B-smoke → **code freeze ≥ 3 h before the demo walk** → W2′ (sighted walk on the frozen build) | Aritro | W2′ meets D12 on the frozen build |
| E: rehearsal | Start by 18:15 CDT | §4 go/no-go → **W4 blindfolded rehearsal** | All three | W4 passes |
| Demo | — | §5 run sheet | All three | — |

If code changes after the freeze, rerun A1 + A5 + B-smoke **and** a sighted W2′. Otherwise there is
no blindfolded walk.

### 1.1 Automated (Mac, no phone): run on every change

| ID | Command (from `ios/`) | What it covers | Pass | Time |
|---|---|---|---|---|
| A1 | `make test` | 965 Swift Testing tests (recount; 1 known geofence issue): lane math, CueDecider hysteresis and rates, geofence skip-ahead, passed-by, arrival plausibility (30 m blob), TurnSettle incl. curb release, StraightWalk, CueSpeechPolicy, CourseSmoother, depth-readiness interlock, ground hazards / signs / hazard watch / GeoJSON, Crown, watch and VLM codecs, route file, sound-recognition lifetime guard, VoiceInputGuard lifecycle, and since Step 34: `TorchSwitchTests` (flashlight settle), `LiveViewTests` (both-cameras `.blockedByRoute`, `FaceTrackingChange`, `DualCameraRotation`), `CueProfileTests` (level × place rules, safety-sign filter), `SpeechResumeTests` (clause resume, 3-resume cap, 0.35 s pause) | exit 0 (`make test`; recount `@Test` before quoting a total) | < 1 min |
| A2 | `make sim` | Swift 6 strict build for the simulator | 0 errors | ~3 min |
| A3 | `make uitest` | 11 XCUITests: start/Next/Repeat/Recenter/Stop, Where am I without a key, haptic buttons + Silence, mount toggle, Cues pickers (Standard / Indoors selected, then Detailed / Outdoors restored), a11y labels and tabs, Navigate to CIF button, empty destination, campus suggestions, plus the tour; the Street View "Where am I" test is skipped unless run with `make uitest-streetview` | 10 passed + 1 skipped, 0 failures | ~4 min |
| A4 | `make tour` | PNG per screen state → `build/shots` | Every PNG reviewed: no truncated pill ("SPEAKI…"), no hyphenated "Recen-ter", instruction not clipped | ~3 min |
| A5 | `make e2e` (or `SCENARIO=clean`) | GPS replay through the real app on the iPhone 17 Pro Max / iOS 27 simulator; asserts on the JSONL log. Report: `build/e2e/report.json` | 4/4 PASS | ~20 min |
| A6 | `python3 scripts/e2e.py --scenario clean --speed 1.0` | Same `clean` path at walking pace (the default 4 m/s makes the distance-based turn-settle release fire before the 25 s moving-time one) | PASS | ~19 min |
| A7 | `python3 scripts/cue_audit.py --selftest` (the first half of `make audit`) | The audit script's fixture checks: wall / overhang / dropout head cells, mounted tilt verdict, replays with and without `resume_from`, the end → next-start pause count, a `field_kind` collision | prints `cue_audit selftest: ok` | < 5 s |

What `make e2e` asserts (from `scripts/e2e.py`), so a failure is easy to read:

- **All scenarios**: a `route` start, `arrived`, waypoints in ascending order, the trip summary
  spoken ("kilometers" or "meters,").
- **clean**: waypoint indices exactly 1..9; wrist cues exactly `turnRight, turnRight, crossing,
  crossing, crossing, arrived`; 0 "Veer"; 0 "Passed".
- **missed_fence**: WP2 is passed 22 m off (outside the 15 m fence, inside 2r = 30 m) and WP8 is
  skipped 28 m north. Needs at least one "Passed …" line that uses a place name, not a sentence.
- **gps_jitter**: ±6 m noise on a fix every 5 m. At most 3 "Veer" lines, and it still arrives.
- **wrong_turn**: overshoots 60 m west at Goodwin, then comes back. Needs at least one
  "Veer right.", and it still arrives.

**What the simulator can't show you** (so these are device tests):

- **Accuracy is fixed in the simulator**, so "GPS weak", the arrival plausibility check and the
  curb release (two stationary fixes) never happen there. The unit tests cover their logic.
- **There's no compass**, so heading comes from course only.
- **None of the hardware exists there**: LiDAR, haptics, beacon audio, AirPods, the watch, Live
  Activity rendering, thermal state.

**When to run what.** Every code change: A1 + A2. Every UI change: + A3 + A4. Every change to
nav, speech or the route file: + A5. Every change to `cue_audit.py` or to a trip-log field it reads:
+ A7. Before each phone install: A1 + A2 + `make e2e SCENARIO=clean`. Before code freeze: A1–A7.

### 1.2 Bench (indoors, phone plugged in, ISR lobby)

Runs the D-tests that don't need GPS: D1–D8, D10, D11, D13, D15–D23, plus F10, F11 and the bench
part of F12. (D23 needs a route running, which needs a GPS fix: stand by a window or use the lobby
door.)

- **Thermal and battery numbers from the bench don't count**, because charging heats the phone.
- **Screen-record every bench session** so you capture the pills that §0.4 says aren't logged (the
  debug footer is gone, so fps is not visible anywhere).
- **Bench smoke (B-smoke, 20 min)** runs after every reinstall: D1 wall, D2 four patterns, D5 head,
  D10(a)(b), D11(a)(c), D19(a), D23(a) one cut.

### 1.3 Outdoor walks

| ID | What | Who | Pass |
|---|---|---|---|
| W1 | **Survey walk, sighted.** Start route to CIF (GPS only logs while a route runs) and stand **30 s still** at the outdoor side of the ISR canopy (WP1), the plaza-to-sidewalk junction (WP2), the pedestrian corners at WP3/4/6/7, WP5, the CIF path turn (WP8) and the CIF east door (WP9). At each corner, pace the distance from the curb to the OSM node and write it down. Mark tree-canopy stretches for F1. | Aarav walks, Aritro logs | For each stop, the "stop" script (§1.4) prints the offset to the JSON coordinate. Offset > 8 m on WP1/2/8/9 → Aritro edits `route_isr_cif.json` and reruns A1 + A5. Curb > 10 m from the node → that crossing releases by heading or after 25 s of moving, not at the curb (note it for F2). |
| W2 | **Reference walk, sighted, app running.** Normal pace, no injected faults; film it with the second phone. Includes D9 (auto-recenter), D12, D13, D14. | Aarav walks, Aritro films, Sagar spots | D12 pass criteria |
| W3 | **Stress walk.** The same route with the scripted faults F1, F2, F3, F6, F7, F8 (one segment), F9 (one segment), F12 (at WP5). Run it ≥ 30 min unplugged in the sun, which doubles as F5. | All three | §3 criteria; the route still completes |
| W4 | **Blindfolded rehearsal** after a full §4 go/no-go. Same protocol as the demo. | Aarav walks, Sagar spots, Aritro films | Arrives with ≤ 2 spotter "Stop" interventions and 0 aborts |

Timing for W2/W4: 989 m great-circle, about 1,025 m walked. At 0.8 m/s that's 21.4 min of walking,
plus about 2.3 min waiting at crossings, so **~24 min (range 20–30)**. Cumulative checkpoints: WP2
1.7 min · WP3 5.4 · WP4 8.7 (+1 min signal) · WP5 12.4 · WP6 15.0 (+1 min signal) · WP7 18.9 · WP8
22.4 · WP9 ~24. Daylight: solar noon is about 12:50 CDT and sunset about 19:05 CDT, so start W4 by
18:15.

### 1.4 Log toolkit (Aritro)

**Getting the log off the phone.** Plugged in, or on the same Wi-Fi once paired. Check the flags with
`xcrun devicectl device copy from --help` before relying on them:

```sh
cd ios; mkdir -p logs
xcrun devicectl device info files --device $DEVICE --domain-type appDataContainer \
  --domain-identifier com.aritro.canekit --subdirectory Documents
xcrun devicectl device copy from --device $DEVICE --domain-type appDataContainer \
  --domain-identifier com.aritro.canekit --source Documents/<file>.jsonl --destination logs/<file>.jsonl
```

Fallback: Xcode → Devices and Simulators → the phone → OpenCane → ⋯ → Download Container. Without
the Mac (§0.1): Files → On My iPhone → OpenCane → AirDrop (trip logs, and `hazards/` for the hazard
map).

**What's in the log.** One file per app launch: `canekit-<ISO time with - for :>.jsonl`. Every line
has `t` (seconds since launch) and `kind`:

- `session` · `start` {lidar, mesh, haptics, vision, launch, face_head_tracking, danger_sounds,
  cue_level, cue_place, obstacle_names, …} · `route` {action start|stop, name, waypoints, headphones,
  watch}
- `gps` {lat, lon, acc, speed} ~1 Hz, only while a route runs · `waypoint` {index = the 1-based
  waypoint reached} · `navcue` {cue} · `arrived`
- `speech` {text, priority obstacle|safety|nav, repeat?} — written only for cue / obstacle / route
  lines, **not** for flashlight, refusal or describer lines · `cue` {cue center|left|right|head|clear,
  ar_t, distance?}
- `speech_dispatch` {text (the whole line), priority, replays, resume_from} for **every** line handed
  to a voice backend (Step 34; `resume_from` Step 37) · `speech_end` {priority} at every natural line
  end (Step 37) · `speech_suppressed` {text, load, reason} for a dropped obstacle name. Dispatched is
  not the same as heard.
- `torch` {action request_on|request_off|unsupported, active} per press, then {action
  confirmed(on: true)|failed(requested: true)|changedByDevice(on: false)…, active, text, error?} per
  spoken outcome (Step 34)
- `both_cameras` {action start|stop|depth_after|refused_route|refused_route_start|unsupported|
  start_failed_recovered|off_for_route|off_background…; on start: front_rotation, back_rotation,
  front_capture_angle, back_capture_angle, front_size, back_size, front_portrait, back_portrait,
  front_mirrored, front_frames, back_frames, hardware_cost, thermal} · `face_tracking` {enabled,
  supported} or {action refused_route|refused_route_start, requested} · `cue_profile` {level, place,
  text}
- `lanes` at 2 Hz {head[3], torso[3] (−1 = no data or clear), trusted, omega, cue, thermal, battery,
  mesh, tilt, fps}
- `audioroute` {connected, name} · `recenter` {auto?} · `repeat` · `watch` {command | test} ·
  `describe` {provider} · `destination` {name, meters, waypoints} (a MapKit route was chosen)
- No field ever replaces a record's own `t` or `kind` (older builds let `cue` / `hazard` fields
  named `kind` overwrite it; a colliding field is now written as `field_kind`)
- `hazard` {type, text, source ground|sign|vision}; the same hazard with GPS and photo goes to
  `Documents/hazards/hazards-<session>.geojson`

```sh
L=logs/canekit-….jsonl
# timeline without the 2 Hz / 1 Hz noise
jq -r 'select(.kind!="lanes" and .kind!="gps") | [(.t*10|round/10), .kind, (.text // .cue // .index // .action // .command // .test // "")] | @tsv' $L
# navigation words that matter
jq -r 'select(.kind=="speech" and (.text|test("^(Veer|Passed|GPS)"))) | "\(.t)\t\(.text)"' $L
# GPS quality: n, median, p90, max, fixes worse than the 20 m gate
jq -s '[.[]|select(.kind=="gps" and .acc>=0)|.acc]|sort|{n:length,p50:.[length/2|floor],p90:.[length*0.9|floor],max:.[-1],over20:(map(select(.>20))|length)}' $L
# thermal + battery once a minute (iOS may report battery in 5 % steps)
jq -r 'select(.kind=="lanes") | "\(.t|floor)\t\(.thermal)\t\(.battery)"' $L | awk -F'\t' '$1>=n{print; n=$1+60}'
# sweep gate: share of untrusted depth samples, peak |ω|
jq -s '[.[]|select(.kind=="lanes")] | {n:length, untrusted:(map(select(.trusted==false))|length), max_omega:(map(.omega)|max)}' $L
# head-height episodes (expect one line per episode, ≥ 4 s apart)
jq -r 'select(.kind=="speech" and .text=="Head height.") | .t' $L
```

**Fence script.** How far from the waypoint node each waypoint fired (run it from the repo root):

```sh
python3 - "$L" <<'EOF'
import json, math, sys
wps = json.load(open("ios/CaneKit/Resources/route_isr_cif.json"))["waypoints"]
def d(a, b):
    p1, p2 = map(math.radians, (a[0], b[0])); dl = math.radians(b[1] - a[1])
    h = math.sin((p2 - p1) / 2) ** 2 + math.cos(p1) * math.cos(p2) * math.sin(dl / 2) ** 2
    return 2 * 6371000 * math.asin(math.sqrt(h))
pending = []    # the triggering fix's `gps` line is written right AFTER its `waypoint` line
for line in open(sys.argv[1]):
    try: e = json.loads(line)
    except ValueError: continue
    if e["kind"] == "waypoint": pending.append(e)
    elif e["kind"] == "gps" and pending:
        for p in pending:
            w = wps[p["index"] - 1]
            print(f'WP{w["id"]} t={p["t"]:.0f}s {d((e["lat"], e["lon"]), (w["lat"], w["lon"])):.1f} m from node '
                  f'(r={w["radius_m"]}) acc={e["acc"]:.0f} speed={e["speed"]:.1f}')
        pending = []
EOF
```
The simulator `clean` replay at 4 m/s prints every waypoint at ≤ its radius (at 4 m/s, WP2 fires at
about 13 m). On the phone, a turn waypoint that fires at more than radius + 5 m past the corner fails
D12.

**Stop script** for W1. It finds the 30 s standing stops and prints each one's offset from the
nearest waypoint:

```sh
python3 - "$L" <<'EOF'
import json, math, statistics as st, sys
wps = json.load(open("ios/CaneKit/Resources/route_isr_cif.json"))["waypoints"]
def d(a, b):
    p1, p2 = map(math.radians, (a[0], b[0])); dl = math.radians(b[1] - a[1])
    h = math.sin((p2 - p1) / 2) ** 2 + math.cos(p1) * math.cos(p2) * math.sin(dl / 2) ** 2
    return 2 * 6371000 * math.asin(math.sqrt(h))
fixes = []
for line in open(sys.argv[1]):
    try: e = json.loads(line)
    except ValueError: continue
    if e["kind"] == "gps": fixes.append(e)
stops, cur = [], []
for f in fixes + [{"speed": 9, "acc": -1}]:
    if f["speed"] < 0.3 and 0 <= f["acc"] <= 10: cur.append(f)
    else:
        if len(cur) >= 20: stops.append(cur)
        cur = []
for s in stops:
    p = (st.median(f["lat"] for f in s), st.median(f["lon"] for f in s))
    w = min(wps, key=lambda w: d(p, (w["lat"], w["lon"])))
    print(f'stop t={s[0]["t"]:.0f}s n={len(s)} {p[0]:.6f},{p[1]:.6f} acc~{st.median(f["acc"] for f in s):.0f} '
          f'-> WP{w["id"]} off by {d(p, (w["lat"], w["lon"])):.1f} m')
EOF
```

---

## 2. Device test matrix

Each test lists: **Where/Who · Steps · Expect · Pass · Log**. The pass numbers are hard; any fail
goes on the bug list with its log file name and video timestamp.

### D1 LiDAR lanes through the clamp: bench · Sagar (mount), Aritro (reads)
- **Steps.**
  1. Clamp the phone on the cane and hold the cane at the walker's normal angle, tip on the floor.
     Read the Mount card's first line and click the hinge until it says "Camera tilt N° down, good"
     (3–8° down; hardware/mount/DESIGN.md).
  2. Face a flat wall at 0.5, 1.0, 1.5 and 2.0 m (tape from the lens). Read all six tiles for 10 s
     at each distance.
  3. Put a box or hand at torso height 0.8 m ahead in the left third, then the right third.
  4. Point at open space for 60 s.
- **Expect.** Tiles show the 10th-percentile depth. The bottom 25 % of the image is skipped as
  ground. Status shows "Depth OK" and the pill "Trusted".
- **Pass.**
  - At 1.0 m all six tiles read **0.8–1.2 m**; at the other distances ±0.2 m.
  - The left obstacle turns only the Left tiles below 1.2 m. If it turns the Right tiles, set
    "Mirror left / right" and record the final setting.
  - Open space: all torso tiles ≥ 2.0 m and **0 `cue` events in 60 s**. If the floor shows in the
    torso row, the mount angle is wrong and would run the Geiger loop forever: check the tilt line
    (at ~10° down or more the torso lanes read pavement near 2 m). Sagar re-angles.
  - Depth keeps up for 60 s: the Mount card shows ~30 fps and `lanes` records (with `fps` and
    `tilt`) are continuous at 2 Hz.
- **Log.** `lanes` torso/head/tilt/fps; `cue` count.
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

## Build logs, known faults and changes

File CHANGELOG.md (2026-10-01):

# Changelog

This submission is Step 69: OpenCane Premium through RevenueCat, on top of the cane demo.

- Product `opencane_premium_annual`, $49.99/year, with a one-month free introductory offer.
- Entitlement `premium`. Offering `default`.
- Always free: obstacle detection, haptics, spatial audio, speech, navigation, emergency calling.
- Premium: Hazard watch (cones, barriers, scooters), Name people ahead, and Family Alerts. The paywall does not open during a walk.
- The step-by-step build log from earlier steps is in git history (`git log`).

## Test on device

Fresh install: splash, onboarding, a walk, Hazard watch refused mid-walk, the paywall after the walk stops, a test purchase, Hazard watch on. See [`docs/stress_test_plan.md`](docs/stress_test_plan.md) for the full device matrix.

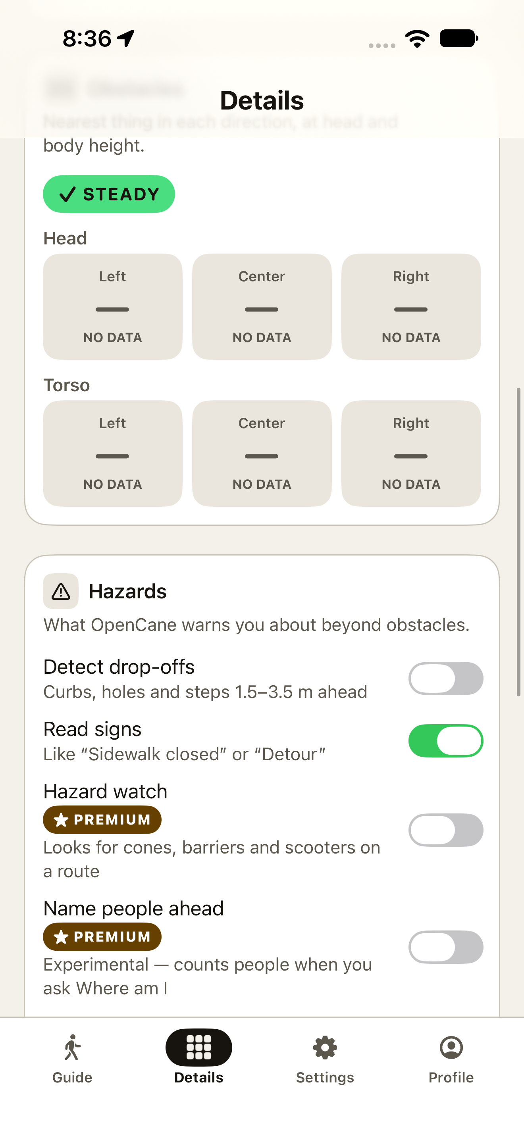
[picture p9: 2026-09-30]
docs/images/hazard-watch.png

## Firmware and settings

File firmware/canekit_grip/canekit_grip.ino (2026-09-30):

/*
 * canekit_grip.ino — CaneKit smart-cane retrofit grip module (hackathon firmware)
 *
 * Boards : Seeed XIAO ESP32-S3 (primary) / ESP32-C3 SuperMini (fallback)
 * BLE    : NimBLE-Arduino 2.x, Nordic UART Service, device name "CANE"
 * Motors : two coin ERM motors via NPN low-side switches, LEDC PWM @ 200 Hz
 * ToF    : optional VL53L1X (see tof.h / tof.cpp, HAS_TOF)
 *
 * RX commands (ASCII, one per line, '\n' or '\r' terminated; a write without a
 * terminator is parsed after 150 ms so nRF Connect "send text" works too):
 *   H:<L|R|B>:<1-4>:<ms>   haptic: motor, intensity 1-4 (40/60/80/100 % duty), duration
 *   P:<n>                  pattern: 1 double pulse both, 2 left triple, 3 right triple,
 *                                   4 long both = STOP (flushes queue first)
 *   S:<0|1>                silence off / on (drops all haptics while on)
 * TX notify every 100 ms:  "D:<mm>,B:<pct>\n"  (-1 when unknown)
 *
 * Fail-safe: no BLE connection for 5 s and ToF present -> LOCAL mode: buzz both
 * motors on drop-off (> baseline+250 mm) or step-up (< 60 % baseline).
 *
 * STATUS: stretch / history only. Cut on when the project went phone-only (AGENTS.md
 * "What this is": no ESP32, no external sensors). The shipping iOS app never talks to it; the
 * only client ever written is ios/stretch/CaneBLE.swift (not in any target), which speaks this
 * exact protocol. Kept so the grip can be revived; the drafts for its housing are cad/.
 * Owner: nobody on the current team. Callers: a BLE central writing NUS RX (CaneBLE.swift, or
 * nRF Connect by hand — firmware/README.md "Testing").
 * Tests: none automated, never built in CI. Manual bench test in firmware/README.md; the
 * drop-off / step-up thresholds below are untuned guesses, never measured on a cane.
 * Threading: NimBLE callbacks run on the NimBLE host task; everything else runs in loop().
 * The only data crossing is `connected`, `lastConnMs` and the RX ring (see below).
 */
#include <Arduino.h>
#include <NimBLEDevice.h>
#include "tof.h"

// ---------------------------------------------------------------- pin maps
#if defined(ARDUINO_XIAO_ESP32S3) || defined(CONFIG_IDF_TARGET_ESP32S3)
  #define BOARD_NAME     "XIAO ESP32-S3"
  #define MOTOR_L_PIN    1      // D0 -> 1k -> NPN base (left motor)
  #define MOTOR_R_PIN    2      // D1 -> 1k -> NPN base (right motor)
  #define LED_PIN        21     // on-board user LED (active LOW)
  #define LED_ACTIVE_LOW 1
  #define I2C_SDA_PIN    5      // D4 (verified: Seeed wiki pin multiplexing page)
  #define I2C_SCL_PIN    6      // D5
  // #define BAT_SENSE_PIN 3    // D2 — uncomment only if a divider is fitted (README)
#elif defined(CONFIG_IDF_TARGET_ESP32C3)
  #define BOARD_NAME     "ESP32-C3 SuperMini"
  #define MOTOR_L_PIN    2
  #define MOTOR_R_PIN    3
  #define LED_PIN        8      // on-board LED (active LOW) — clashes with default SDA, so I2C moved
  #define LED_ACTIVE_LOW 1
  #define I2C_SDA_PIN    6
  #define I2C_SCL_PIN    7
  // #define BAT_SENSE_PIN 0    // ADC1_CH0
#else
  #error "Unsupported board: build for XIAO ESP32-S3 or ESP32-C3"
#endif

// Battery divider ratio: multiply the ADC-pin voltage by this to get the cell voltage.
#define BAT_DIV_RATIO   2.0f  // (R_top+R_bot)/R_bot, e.g. 100k/100k -> 2.0
#define PWM_FREQ        200   // Hz, per spec (ERM motors are fine here; 200 Hz is audible-ish)
#define PWM_RES         8     // bits -> duty 0..255

// ---------------------------------------------------------------- BLE (NUS)
#define NUS_SVC "6E400001-B5A3-F393-E0A9-E50E24DCCA9E"
#define NUS_RX  "6E400002-B5A3-F393-E0A9-E50E24DCCA9E"  // phone -> cane (write)
#define NUS_TX  "6E400003-B5A3-F393-E0A9-E50E24DCCA9E"  // cane -> phone (notify)

// TX (notify) characteristic, created in bleSetup(); telemetry is pushed through it from loop().
static NimBLECharacteristic* txChar = nullptr;
// True between onConnect and onDisconnect. Written on the NimBLE host task, read in loop().
static volatile bool connected = false;
static uint32_t lastConnMs = 0;          // last time we were connected (for 5 s fail-safe)

// RX bytes arrive on the NimBLE host task; hand them to loop() via a SPSC ring.
// Single-producer / single-consumer: only RxCB::onWrite advances rxHead, only rxUpdate() advances
// rxTail, so no lock is needed. One slot is always left empty (full = head+1 == tail), so the ring
// holds 255 bytes; bytes past that are dropped silently (a burst of > 255 bytes between loops).
static uint8_t  rxRing[256];
static volatile uint8_t rxHead = 0, rxTail = 0;

// Connection state. On disconnect it restarts advertising at once (NimBLE stops advertising
// while connected) and stamps lastConnMs so the 5 s local-mode delay counts from the drop.
class ServerCB : public NimBLEServerCallbacks {
  void onConnect(NimBLEServer*, NimBLEConnInfo&) override { connected = true; }
  void onDisconnect(NimBLEServer*, NimBLEConnInfo&, int) override {
    connected = false; lastConnMs = millis();
    NimBLEDevice::startAdvertising();
  }
};
// RX writes: copy bytes into the ring and return quickly; parsing happens in loop() (rxUpdate).
class RxCB : public NimBLECharacteristicCallbacks {
  void onWrite(NimBLECharacteristic* c, NimBLEConnInfo&) override {
    NimBLEAttValue v = c->getValue();
    for (size_t i = 0; i < v.length(); i++) {
      uint8_t next = rxHead + 1;            // uint8_t wraps at 256 = ring size
      if (next == rxTail) break;            // full: drop
      rxRing[rxHead] = v.data()[i]; rxHead = next;
    }
  }
};

// NUS peripheral named "CANE": RX accepts write and write-without-response, TX notifies. The
// service UUID is advertised so a central can scan for NUS (CaneBLE.swift also matches the name).
// MTU 64 is ample: the longest valid command ("H:B:4:10000") is 11 bytes, telemetry < 24.
static void bleSetup() {
  NimBLEDevice::init("CANE");
  NimBLEDevice::setMTU(64);
  NimBLEServer* srv = NimBLEDevice::createServer();
  srv->setCallbacks(new ServerCB());
  NimBLEService* svc = srv->createService(NUS_SVC);
  txChar = svc->createCharacteristic(NUS_TX, NIMBLE_PROPERTY::NOTIFY);
  NimBLECharacteristic* rx = svc->createCharacteristic(NUS_RX, NIMBLE_PROPERTY::WRITE | NIMBLE_PROPERTY::WRITE_NR);
  rx->setCallbacks(new RxCB());
  svc->start();
  NimBLEAdvertising* adv = NimBLEDevice::getAdvertising();
  adv->setName("CANE");
  adv->addServiceUUID(NUS_SVC);
  adv->enableScanResponse(true);
  adv->start();
}

// ---------------------------------------------------------------- motors / haptics
// Motor bit mask: bit 0 left, bit 1 right; both = 3.
enum { M_L = 1, M_R = 2, M_B = 3 };
struct Step { uint8_t mask, duty; uint16_t ms; };            // ms == 0 terminates a sequence
static const uint8_t DUTY[5] = { 0, 102, 153, 204, 255 };    // intensity 0..4 -> 0/40/60/80/100 %

// Built-in patterns: {mask, 255 = full duty, ms} buzzes, {0,0,ms} pauses, {0,0,0} ends the sequence.
// PAT_DOUBLE = P:1 and the local drop-off alert; PAT_STOP = P:4; PAT_STEPUP = local step-up alert.
static const Step PAT_DOUBLE[]  = { {M_B,255,120}, {0,0,100}, {M_B,255,120}, {0,0,0} };
static const Step PAT_LTRIPLE[] = { {M_L,255,100}, {0,0,80}, {M_L,255,100}, {0,0,80}, {M_L,255,100}, {0,0,0} };
static const Step PAT_RTRIPLE[] = { {M_R,255,100}, {0,0,80}, {M_R,255,100}, {0,0,80}, {M_R,255,100}, {0,0,0} };
static const Step PAT_STOP[]    = { {M_B,255,700}, {0,0,0} };
static const Step PAT_STEPUP[]  = { {M_B,255,400}, {0,0,0} };     // local-mode only
// Indexed by the P:<n> number (1..4); index 0 unused. PAT_STEPUP is not reachable from BLE.
static const Step* const PATTERNS[] = { nullptr, PAT_DOUBLE, PAT_LTRIPLE, PAT_RTRIPLE, PAT_STOP };

// Command queue: up to 4 pending commands (each = one H step or one pattern).
struct Cmd { const Step* seq; Step single; };
#define QUEUE_LEN 4
// Ring of pending commands: qHead = oldest, qCount = how many. The playing command is NOT in the
// queue (it moved to curSeq), so up to 4 wait behind the one playing. Loop-only state.
static Cmd     queue[QUEUE_LEN];
static uint8_t qHead = 0, qCount = 0;
static const Step* curSeq = nullptr;   // sequence being played (nullptr = idle)
static Step    oneShot[2];             // storage for an H command while it plays
// Index of the playing step inside curSeq.
static uint8_t curIdx = 0;
// millis() at which the playing step ends.
static uint32_t stepEndMs = 0;
// S:1 state. ⚠ Sticky across disconnects: a phone that sets S:1 and then drops leaves the grip
// silent, and local fail-safe alerts are also skipped while silenced (see loop()).
static bool silenced = false;

// One motor's PWM duty (0..255). Arduino-ESP32 3.x addresses LEDC by pin; 2.x by channel
// (left = channel 0, right = 1, attached in motorsSetup).
static void motorWrite(uint8_t pin, uint8_t duty) {
#if ESP_ARDUINO_VERSION_MAJOR >= 3
  ledcWrite(pin, duty);                        // core 3.x: pin-based API
#else
  ledcWrite(pin == MOTOR_L_PIN ? 0 : 1, duty); // core 2.x: channel-based API
#endif
}
// Attach both motor pins to LEDC at PWM_FREQ / PWM_RES and start them off.
static void motorsSetup() {
#if ESP_ARDUINO_VERSION_MAJOR >= 3
  ledcAttach(MOTOR_L_PIN, PWM_FREQ, PWM_RES);
  ledcAttach(MOTOR_R_PIN, PWM_FREQ, PWM_RES);
#else
  ledcSetup(0, PWM_FREQ, PWM_RES); ledcAttachPin(MOTOR_L_PIN, 0);
  ledcSetup(1, PWM_FREQ, PWM_RES); ledcAttachPin(MOTOR_R_PIN, 1);
#endif
  motorWrite(MOTOR_L_PIN, 0); motorWrite(MOTOR_R_PIN, 0);
}
// Drive the motors in `mask` at `duty` and turn the others off (a step's whole motor state).
static void motorsApply(uint8_t mask, uint8_t duty) {
  motorWrite(MOTOR_L_PIN, (mask & M_L) ? duty : 0);
  motorWrite(MOTOR_R_PIN, (mask & M_R) ? duty : 0);
}
// Flush the queue, abandon the playing sequence and stop both motors. Used by P:4, S:1 and a
// local-mode alert (so the alert is never stuck behind queued phone commands).
static void hapticStopAll() { qCount = 0; curSeq = nullptr; motorsApply(0, 0); }

// Returns false only when the queue is full (the parser then logs "rejected"). While silenced the
// command is accepted and discarded, so S:1 never produces rejection noise.
static bool enqueue(const Cmd& c) {
  if (silenced) return true;                   // accepted, silently dropped
  if (qCount >= QUEUE_LEN) return false;
  queue[(qHead + qCount) % QUEUE_LEN] = c; qCount++;
  return true;
}
// Queue one H: buzz (motor mask, duty 0..255, duration ms).
static bool enqueueStep(uint8_t mask, uint8_t duty, uint16_t ms) {
  Cmd c; c.seq = nullptr; c.single = { mask, duty, ms }; return enqueue(c);
}
// Queue a built-in pattern (a static, {0,0,0}-terminated Step array).
static bool enqueuePattern(const Step* seq) { Cmd c; c.seq = seq; return enqueue(c); }

// Apply curSeq[curIdx] to the motors and set its end time.
static void startStep() {
  const Step& s = curSeq[curIdx];
  motorsApply(s.mask, s.duty);
  stepEndMs = millis() + s.ms;
}
// Non-blocking scheduler: advance the current sequence, then pull the next command.
static void hapticUpdate() {
  uint32_t now = millis();
  if (curSeq && (int32_t)(now - stepEndMs) >= 0) {
    curIdx++;
    if (curSeq[curIdx].ms == 0) { curSeq = nullptr; motorsApply(0, 0); }
    else startStep();
  }
  if (!curSeq && qCount) {
    Cmd& c = queue[qHead]; qHead = (qHead + 1) % QUEUE_LEN; qCount--;
    if (c.seq) curSeq = c.seq;
    else { oneShot[0] = c.single; oneShot[1] = {0,0,0}; curSeq = oneShot; }
    curIdx = 0; startStep();
  }
}

// ---------------------------------------------------------------- command parser
// The line being assembled from RX bytes (47 chars + NUL; extra characters are dropped, so an
// over-long line is parsed truncated), its length, and millis() of its last appended byte.
static char     line[48];
static uint8_t  lineLen = 0;
static uint32_t lineTs = 0;

// Parse and act on one command line (leading spaces skipped, command letter case-insensitive),
// echo it to Serial, and log a rejection for bad syntax, out-of-range values or a full queue.
// Unknown letters are rejected too. Runs in loop() only.
static void handleLine(char* s) {
  while (*s == ' ') s++;
  Serial.printf("[rx] %s\n", s);
  bool ok = false;
  switch (toupper(s[0])) {
    case 'H': {                                   // H:<L|R|B>:<1-4>:<ms>
      char m = 0; int lvl = 0; long ms = 0;
      if (sscanf(s + 1, ":%c:%d:%ld", &m, &lvl, &ms) == 3 && lvl >= 1 && lvl <= 4 && ms > 0 && ms <= 10000) {
        uint8_t mask = (toupper(m) == 'L') ? M_L : (toupper(m) == 'R') ? M_R : (toupper(m) == 'B') ? M_B : 0;
        if (mask) ok = enqueueStep(mask, DUTY[lvl], (uint16_t)ms);
      }
      break;
    }
    case 'P': {                                   // P:<1-4>
      int n = 0;
      if (sscanf(s + 1, ":%d", &n) == 1 && n >= 1 && n <= 4) {
        if (n == 4) hapticStopAll();              // STOP: flush everything, then long buzz
        ok = enqueuePattern(PATTERNS[n]);
      }
      break;
    }
    case 'S': {                                   // S:<0|1>
      int n = -1;
      if (sscanf(s + 1, ":%d", &n) == 1 && (n == 0 || n == 1)) {
        silenced = (n == 1);
        if (silenced) hapticStopAll();
        ok = true;
      }
      break;
    }
  }
  if (!ok) Serial.println("[rx] rejected (bad syntax or queue full)");
}
// Drain the RX ring into `line`; CR or LF ends a line (a CRLF pair yields one line, empty ones
// are ignored).
static void rxUpdate() {
  while (rxTail != rxHead) {
    char c = (char)rxRing[rxTail]; rxTail++;
    if (c == '\n' || c == '\r') { if (lineLen) { line[lineLen] = 0; handleLine(line); } lineLen = 0; }
    else if (lineLen < sizeof(line) - 1) { line[lineLen++] = c; lineTs = millis(); }
  }
  // No terminator within 150 ms -> treat what we have as a complete line.
  if (lineLen && millis() - lineTs > 150) { line[lineLen] = 0; handleLine(line); lineLen = 0; }
}

// ---------------------------------------------------------------- battery
// Battery percentage 0..100 from 8 averaged ADC reads, or -1 when BAT_SENSE_PIN is not defined.
// Linear 3.3 V = 0 % .. 4.2 V = 100 % (crude; a LiPo is not linear). Sampled once a second in loop().
static int batteryPct() {
#ifdef BAT_SENSE_PIN
  uint32_t mv = 0;
  for (int i = 0; i < 8; i++) mv += analogReadMilliVolts(BAT_SENSE_PIN);
  float v = (mv / 8.0f) * BAT_DIV_RATIO / 1000.0f;          // volts at the cell
  int pct = (int)((v - 3.3f) / (4.2f - 3.3f) * 100.0f + 0.5f); // crude linear LiPo map
  return constrain(pct, 0, 100);
#else
  return -1;                                                  // XIAO S3 has no battery ADC by default
#endif
}

// ---------------------------------------------------------------- local (fail-safe) mode
// Local fail-safe tuning. ⚠ Untuned guesses from the original spec, never measured on a cane:
//   LOCAL_MODE_DELAY_MS  ms without a phone before local mode starts
//   BASE_N               readings in the baseline window (at the 50 ms feed rate, ~1 s)
//   STABLE_SPREAD_MM     window max-min allowed for the baseline to update
//   DROPOFF_MM           rise above baseline that counts as a drop-off
//   ALERT_COOLDOWN_MS    minimum ms between local alerts
#define LOCAL_MODE_DELAY_MS  5000
#define BASE_N               20
#define STABLE_SPREAD_MM     40      // max-min of last 20 readings to count as "stable"
#define DROPOFF_MM           250
#define ALERT_COOLDOWN_MS    1500
// Circular window of the last BASE_N distances (mm) for the baseline, write index and fill count.
static int16_t  hist[BASE_N];
static uint8_t  histIdx = 0, histFill = 0;
// Ground distance (mm) the sensor normally sees; -1 until the first stable window. It is kept, not
// cleared, while readings are unstable, and it re-learns from any surface held steady ~1 s: standing
// still over a step-down makes the lower ground the new baseline.
static int      baseline = -1;
static uint32_t lastAlertMs = 0;
// Recomputed every loop(): no phone for LOCAL_MODE_DELAY_MS and a ToF sensor found at boot.
static bool     localMode = false;

// Feed every valid reading; baseline = median of the last 20 readings while stable.
static void baselineFeed(int d) {
  hist[histIdx] = d; histIdx = (histIdx + 1) % BASE_N;
  if (histFill < BASE_N && ++histFill < BASE_N) return;   // need 20 samples first
  int16_t s[BASE_N]; memcpy(s, hist, sizeof(s));
  for (int i = 1; i < BASE_N; i++) { int16_t v = s[i]; int j = i - 1; while (j >= 0 && s[j] > v) { s[j+1] = s[j]; j--; } s[j+1] = v; }
  if (s[BASE_N-1] - s[0] <= STABLE_SPREAD_MM) baseline = (s[BASE_N/2 - 1] + s[BASE_N/2]) / 2;
}
// One local-mode decision for distance `d` mm: drop-off (d > baseline + 250) -> double pulse,
// step-up / obstacle (d < 60 % of baseline) -> one 400 ms buzz. Flushes the queue first. No-op
// before a baseline exists or within the cooldown.
static void localModeCheck(int d) {
  if (baseline <= 0 || millis() - lastAlertMs < ALERT_COOLDOWN_MS) return;
  bool drop = d > baseline + DROPOFF_MM;
  bool step = d < (baseline * 6) / 10;
  if (drop || step) {
    lastAlertMs = millis();
    Serial.printf("[local] %s d=%d base=%d\n", drop ? "DROP-OFF" : "STEP-UP", d, baseline);
    hapticStopAll();
    enqueuePattern(drop ? PAT_DOUBLE : PAT_STEPUP);
  }
}

// ---------------------------------------------------------------- LED
// Status LED from millis(): solid connected, 125 ms blink in local mode, 100 ms blip per second
// while advertising. Called every loop().
static void ledUpdate() {
  uint32_t t = millis();
  bool on = connected ? true                      // solid: connected
          : localMode ? ((t / 125) & 1)           // fast blink: local fail-safe mode
          : ((t % 1000) < 100);                   // short blip: advertising
  digitalWrite(LED_PIN, LED_ACTIVE_LOW ? !on : on);
}

// ---------------------------------------------------------------- setup / loop
// Arduino entry: serial at 115200, LED, motors, ToF (probe only; absent is fine), BLE advertising.
// lastConnMs starts at boot so local mode needs 5 s of no connection after power-on too.
void setup() {
  Serial.begin(115200);
  pinMode(LED_PIN, OUTPUT);
  motorsSetup();
  bool tof = tofBegin(I2C_SDA_PIN, I2C_SCL_PIN);
  bleSetup();
  lastConnMs = millis();
  Serial.printf("CaneKit grip on %s, ToF %s, advertising as CANE\n", BOARD_NAME, tof ? "OK" : "absent");
}

// Arduino main loop, non-blocking: RX parse, haptic scheduler, ToF poll; baseline feed + local check
// at most every 50 ms; local-mode flag; battery every 1 s; telemetry every 100 ms (only sent while
// connected); LED.
void loop() {
  static uint32_t lastTx = 0, lastBat = 0, lastTofMs = 0;
  static int batPct = -1;
  uint32_t now = millis();

  rxUpdate();
  hapticUpdate();
  tofUpdate();

  int d = tofDistanceMm();
  if (d >= 0 && now - lastTofMs >= 50) { lastTofMs = now; baselineFeed(d); if (localMode && !silenced) localModeCheck(d); }

  if (connected) lastConnMs = now;
  localMode = !connected && tofPresent() && (now - lastConnMs > LOCAL_MODE_DELAY_MS);

  if (now - lastBat >= 1000) { lastBat = now; batPct = batteryPct(); }

  if (now - lastTx >= 100) {                       // telemetry: "D:<mm>,B:<pct>\n"
    lastTx = now;
    char buf[24];
    int n = snprintf(buf, sizeof(buf), "D:%d,B:%d\n", d, batPct);
    if (connected && txChar) { txChar->setValue((uint8_t*)buf, n); txChar->notify(); }
  }
  ledUpdate();
}

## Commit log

2026-09-29 Step 69.1: extend the design system with brand tokens and four components
    Theme.swift already was the design system, so this extends it rather
    than adding a second one: brand navy / gold tokens from the app icon, a
    high-contrast `highlight` accent (>= 7.4:1 on every light surface),
    CKFont.display / title, CKMetrics.minimumTarget (44 pt), and
    CKFeatureRow, CKTextButton, CKPremiumBadge, CKStateMessage for the
    splash, onboarding, paywall and settings work that follows. No existing
    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
2026-09-29 Step 69.2: launch screen and a sub-second splash that never delays the engines
    The launch screen is now the app icon as a rounded tile on the brand
    navy (LaunchLogo + LaunchBackground, rendered by the new
    ios/scripts/launchlogo.py). SplashView repeats that picture and brings
    in the wordmark; RootView is the new window root and removes it on the
    LaunchFlow plan: 0.6 s + 0.25 s fade, a still 0.4 s cut under Reduce
    Motion, and no splash at all under VoiceOver or automation (XCUITests,
    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
2026-09-29 Step 69.3: first-launch onboarding with permissions asked in context
    Four paged screens (the product, LiDAR at waist and head height, haptics
    and spatial audio, permissions) with a pinned Next / Get Started button
    on every page, Skip in the top corner, VoiceOver focus moved to each new
    page title, scrolling pages at accessibility text sizes and no slide
    under Reduce Motion. The last page asks for camera, location and
    microphone, each under one line of why, with Allow / Allowed / Open
    Settings. Notifications are not requested: OpenCane posts none.
    First launch only: ContentView (and AppModel.start()) now waits for Get
    Started / Skip, so the launch line and microphone do not talk over
    VoiceOv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
2026-09-29 Step 69.4: UI pass - plain status words, About card, empty state, avatar
    Details: the depth status card shows plain words from DepthStatusText
    (tested against every DepthEngine.status string) instead of "Depth OK" /
    "No LiDAR / sceneDepth on this device" / "AR error: ..."; the raw strings
    are unchanged in the engine and the trip log. The Hazards card gets an
    empty state. Settings: "Testing tools" becomes "Check your kit", the
    developer "App self-check" row is gone, and a new About group carries
    the version, privacy policy, terms and source links (AppInfo). Profile:
    initials instead of one teammate's bundled photo on every Medical ID.
    MARKETING_VERSION 1.0. No XCUITest label changed.
    Verifie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
2026-09-29 Step 69.5: RevenueCat OpenCane Premium with a paywall that never interrupts a walk
    Adds purchases-ios 5.91.0 (SPM mirror, app target only; the one
    owner-approved exception to hard rule 2) and gates exactly the two
    requested benefits: advanced AI object detection (Hazard watch, Name
    people ahead) and Grok Bot + Family Alerts. Obstacle detection, haptics,
    audio, speech, every warning, navigation and emergency calling stay free.
    - PremiumGate / PaywallPricing (CaneKitLogic, 15 tests written first):
    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
2026-09-29 Step 69.7: review round - fix a compile error, upgraded installs, lapses
    Three adversarial reviewers (compile, regressions + gating,
    accessibility + App Store); every finding verified against the code.
    28 fixed, 2 rejected with reasons, 3 deferred to the owner (CHANGELOG).
    Most important:
    - EntitlementManager used @Observable without import Observation.
    - Upgraded installs no longer see onboarding (LaunchFlow.isPriorInstall),
    which would have held every engine behind silent pages.
    - Family alerts is never sold or switched on without the alert service.
    - A lapse is spoken and undone when Premium returns; nothing is revoked
    or unlocked mid-walk; indoor recording counts as a walk.
    - Automa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
2026-09-30 Show OpenCane Premium in the demo judges will watch.
    The paywall, free month, and screenshots are in the public repo, and the internal pitch notes are gone so the code is what they read.
2026-09-30 Document the public story and strip diary dates from the repo.
    Judges and the next agent should read the code and the README, not a timestamped build log.
    [ball_tip.scad, cane_mount.scad, chest_plate.scad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]
2026-09-30 Repair sentences the date strip left unfinished.
    The hardware note and the ISR route page still read as if a date had been cut out of the middle.
2026-09-30 Say the free month on the paywall and finish the cut-off sentences.
    The StoreKit intro offer is a free month, so the charge disclosure no longer says the price is due at subscribe.
2026-09-30 Point the docs at the Settings labels and Premium switches that ship.
    The next agent was still being told the old names, the old test totals, and that a describe earcon was not built.
2026-09-30 Close the sentences the date strip left half-finished.
    Comments and hardware notes were still ending on a comma or an empty slot where a date used to be.
    [ball_tip.scad, cane_mount.scad, chest_plate.scad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]
2026-09-30 Finish the last cut-off sentences OpenCode found.
    The Details tab, the renewal comment, and a handful of docs still had a date torn out of the middle.
2026-09-30 Say the free month only when this Apple Account can still redeem it.
    Codex flagged the paywall promising the intro offer to returning customers. Also close the leftover cut-off sentences and name the Details tab in the docs.
2026-09-30 Show the free month on the paywall and add the Devpost paste sheet.
    Judges were still looking at a screenshot that charged at subscribe. The price block now says the first month is free when this account can redeem it, and the recaptured shots match.
2026-09-30 Document the free-month rule and refresh the knowledge graph.
    The next agent was still reading a graph that named deleted docs and a paywall note that charged at subscribe. The graph now matches the eligible-account wording and drops those files.
2026-09-30 Keep a Premium purchase that is waiting for approval, and ignore stale subscription answers.
    An Ask to Buy purchase returned .pending and the switch that opened the paywall was forgotten
    once the sheet closed, although the alert promises "Premium turns on as soon as it goes
    through". The paywall now parks it in pendingPremiumFeature, and reconcilePremium keeps a
    pending feature until Premium actually unlocks (PremiumGate.spendsPending).
    A refresh() that started before a purchase could answer after it and set access back to free,
    turning Hazard watch off again. EntitlementManager.apply now drops a CustomerInfo whose
    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
2026-10-01 Remember every Premium switch waiting for approval across relaunches, and ignore a second Subscribe tap.
    Follow-up from the Cursor review of 2728629:
    - pendingPremiumFeature was one in-memory slot. Ask to Buy approval can take hours, so a relaunch
    lost it, and a second pending request overwrote the first. It is now pendingPremiumFeatures, a
    UserDefaults-backed set (premiumPendingFeatures), spent once Premium unlocks.
    - A tap while a purchase was already running returned .pending and parked the switch as if it
    were Ask to Buy. purchase() now returns .alreadyPurchasing, which the paywall ignores.
    make test 967 passed (1 known issue), make sim green.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
2026-10-01 Fix 17 verified demo-review findings across routes, cues, speech, beacon, emergency and Premium.
    A 69-agent review (6 areas, every finding checked by 3 adversarial verifiers) confirmed 20
    bugs; codex then reviewed each fix. Fixed here:
    - Medical ID: the old demo-seed rewrite turned every real "O+" into "A-" on every launch. It now
    runs once, only on the seed (recognised by its "Rolling Ball" cane), and is saved.
    - Premium: Ask to Buy (RevenueCat paymentPendingError) is .pending, not a failed purchase;
    turning a switch off drops it from the pending set; an older answer may not remove Premium,
    but one that grants it always applies (offline answers carry the device clock).
    - Routes: a res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
2026-10-01 Describe on-device straight away when an offline question fails, and only rewrite the exact old demo profile.
    Codex review of the demo-hardening commits: the offline fallback re-ran the cloud first (another
    full timeout on a dead link), and any cane containing "Rolling Ball" was treated as the demo seed.
2026-10-01 Redesign the Premium paywall for conversion: logo hero, proof laurels, Free vs Premium table, trial timeline and a pinned gold call to action.
    The price breakdown sits under the billed price (Apple), the free-month lines appear only when this
    account is eligible, the full renewal terms stay on the page, and the button keeps the "Subscribe"
    identifier. Copy reviewed by codex. make uitest-store passes and shoots the paywall top to bottom.
2026-10-03 Strip machine-local paths from docs
    Two spots leaked a developer's local filesystem layout into tracked
    files. Neither carries information the repo-relative path doesn't.
    - docs/cue_design_v2.md: the cited-files list was written with an
    absolute /Users/<name>/Downloads/54FoundersHack/ prefix. The suffix
    already matches the real tree, so the prefix is pure noise plus a
    username.
    - hardware/mount_screwless/README.md: a Windows user directory in the
    OpenSCAD install note, now %USERPROFILE% to match what
    scripts/build_stl.ps1 already tells you.
